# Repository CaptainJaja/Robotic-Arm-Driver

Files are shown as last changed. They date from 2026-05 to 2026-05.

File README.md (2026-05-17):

# Contrôleur "Rail-Bras-Ventouses" (STM32G4 + TMC2226)

Ce PCB est la carte de contrôle centrale du sous-système de préhension du robot. Elle orchestre les mouvements du rail, du bras et la gestion des ventouses.
Elle intègre une architecture de puissance à plusieurs étages pour gérer différents niveaux de tension (24V, 12V, 7.4V, 3.3V) à partir d'une batterie 6S, tout en pilotant une grande variété d'actionneurs via un **STM32G431**.

## ⚡ Architecture d'Alimentation (Power Tree)

L'alimentation est distribuée en cascade pour optimiser le rendement et la stabilité :

1.  **Entrée Principale :** Batterie LiPo 6S (~22.2V - 25.2V).
2.  **Étage 1 (V_BAT ➔ 12V) :** Buck **TI LM25145**.
    * *Usage :* Alimentation des Dynamixels et source pour les étages suivants.
3.  **Étage 2A (12V ➔ 7.4V) :** Buck **TI TPS563300**.
    * *Usage :* Alimentation de puissance pour les Servomoteurs classiques et les 4 moteurs DC (MCC).
4.  **Étage 2B (12V ➔ 3.3V) :** Module de puissance **Würth Elektronik MagI³C (173010x78)**.
    * *Usage :* Alimentation propre pour la logique (STM32, Capteurs).

## 🧠 Cœur Logique : STM32G431CBU6

* **MCU :** ARM Cortex-M4 à 170 MHz (Série G4 optimisée pour le contrôle moteur/mixte).
* **Programmation :** Connecteur **ST-Link** dédié (SWD).
* **Interface Utilisateur :**
    * 1x LED Power (3.3V).
    * 2x LEDs d'état (pilotables par GPIO).
    * 1x Bouton Reset.
    * 1x Bouton User (connecté sur GPIO/EXTI).

## 🦾 Contrôle Actionneurs

### 1. Axe "Rail" (Stepper) - TMC2226-SA
* **Driver :** Trinamic TMC2226 (Ultra-Silent).
* **Tension :** 24V (V_BAT).
* **Configuration :**
    * **Rsense :** 390 mΩ (Définit la plage de courant : Irms=0.56A).
    * **Microstepping :** Configurable via **DIP Switch** embarqué.
    * **Interface :** STEP / DIR + UART (Diag).
* **❄️ Gestion Thermique Avancée :**
    * Le Pad thermique du TMC2226 est soudé sur un large plan de cuivre.
    * Réseau de **vias thermiques** traversant le PCB vers une zone de cuivre exposée sur la face opposée.
    * Emplacement prévu pour coller une ailette de refroidissement (heatsink) directement sur la zone arrière.

### 2. Bras & Ventouses
* **2x Servomoteurs :** Alimentés en 7.4V (PWM direct).
* **2x Dynamixels :** Connecteurs dédiés (GND, 12V, Data).
    * *Protocole :* UART Half-Duplex (compatible protocole Robotis).
* **4x Moteurs DC (MCC) :** Sorties alimentées en 7.4V (pour pompes à vide/ventouses).

## 🔌 Connectivité & Capteurs

* **Capteur ToF (Time of Flight) :** Connecteur dédié (I2C + GPIOs + 3.3V).
* **Expansions :** 3 rangées de headers [GND - 3V3 - GPIO] pour ajouts futurs.

## 🐛 Debug & Instrumentation

Le PCB intègre des points de test (headers) regroupés pour faciliter l'analyse à l'oscilloscope ou à l'analyseur logique :

* `PWM_Servo1`, `PWM_Servo2`
* `UART_Dynamixel1`, `UART_Dynamixel2`
* `STEP`, `PDN`, `INDEX`, `DIAG` (Signaux du TMC2226)

## 🛠️ Vues du PCB

| Face Composants | Face Cuivre |
| :---: | :---: |
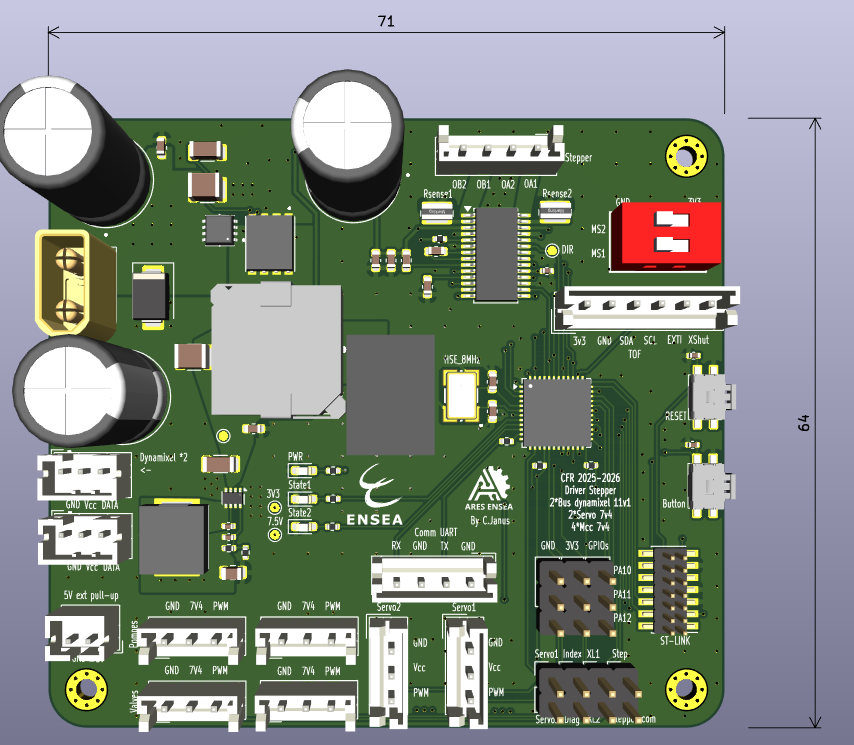
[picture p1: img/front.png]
PCB Face
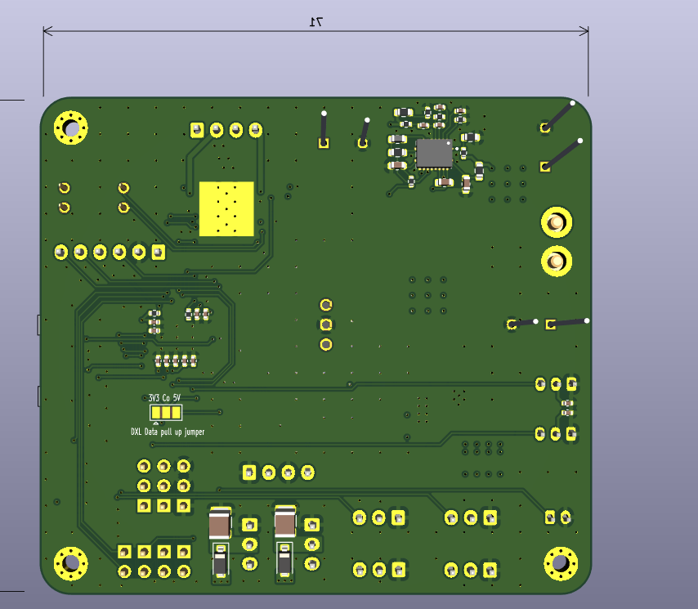
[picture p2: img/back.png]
PCB Dos
|  |  |

---
## License

This hardware project is licensed under the **CERN Open Hardware Licence Version 2 - Strongly Reciprocal (CERN-OHL-S v2)**.

You may redistribute and modify this documentation and make products using it under the terms of the CERN-OHL-S v2. If you modify or distribute this design, you must share your modifications and the entire product it is integrated into under the same open-source license.

Designed by C. Janus.

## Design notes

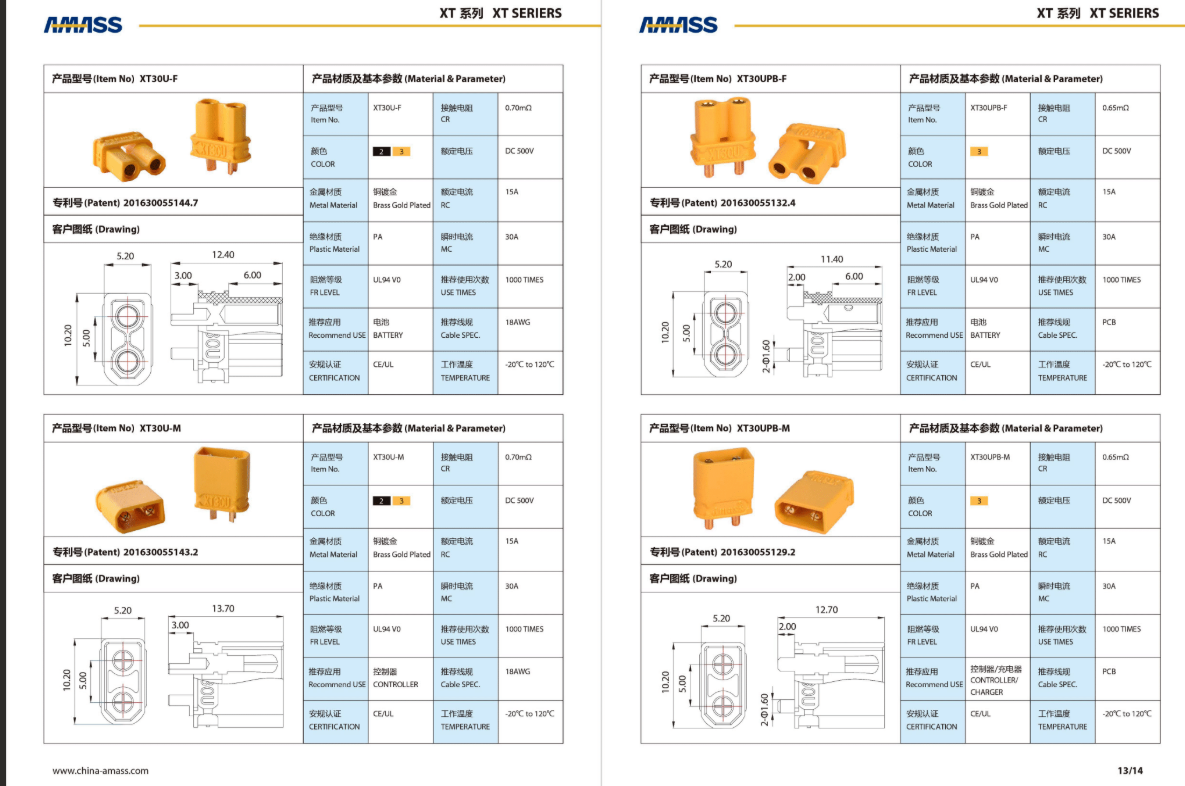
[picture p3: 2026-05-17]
datasheets/Specs_XT30.png

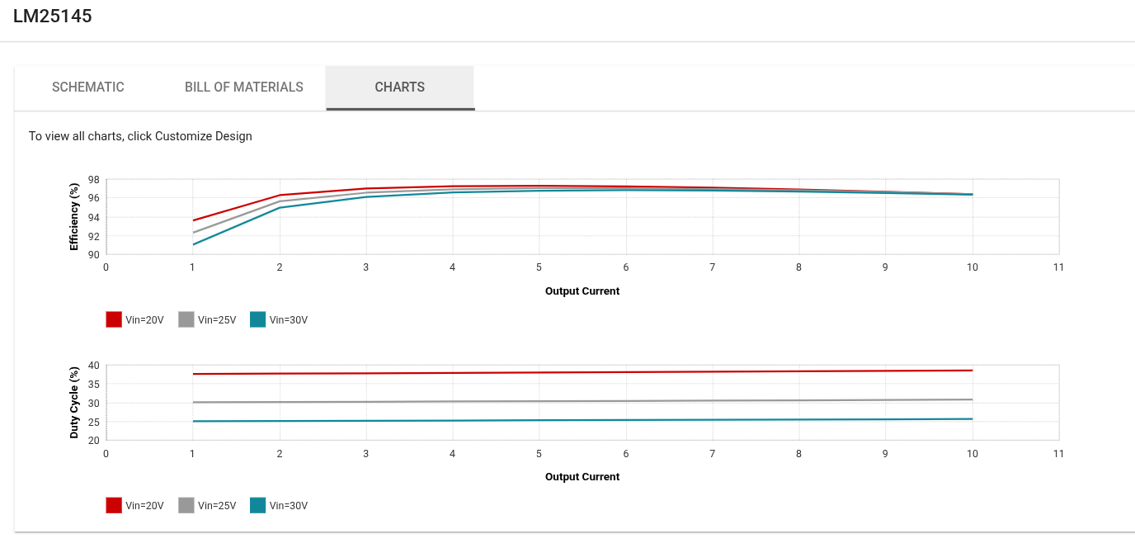
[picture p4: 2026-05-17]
Capture d’écran du 2025-11-26 16-49-32.png

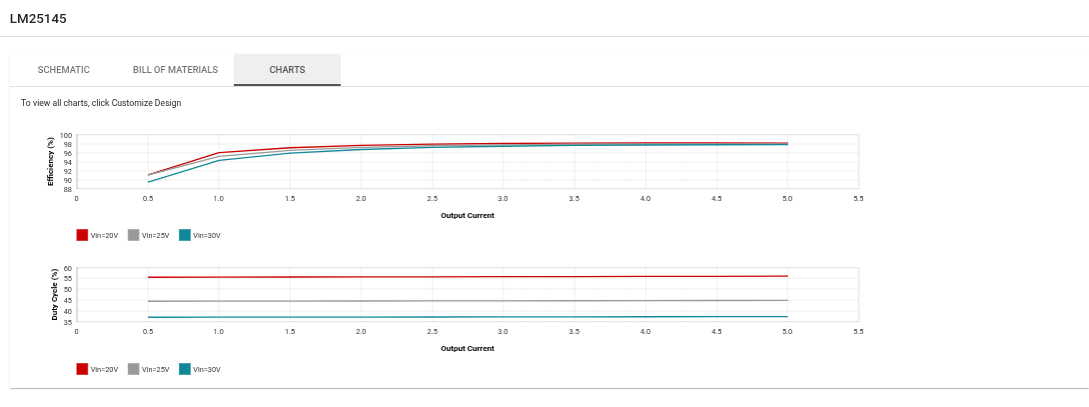
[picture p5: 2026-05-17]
Buck_11v1_XL430/charts.png

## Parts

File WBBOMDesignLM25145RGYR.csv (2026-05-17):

Part | Manufacturer | Part Number | Quantity | Price ($) | Footprint (mm²) | Description
Cbst | TDK | CGA3E2X7R1H104K080AA | 1 | 0.01 | 4.68 | Cap: 100 nF Total Derated Cap: 72 nF VDC: 50 V ESR: 29.6 mΩ Package: 0603
Ccomp1 | MuRata | GRM155R71C822KA01D | 1 | 0.01 | 3 | Cap: 8.2 nF Total Derated Cap: 8.2 nF VDC: 16 V ESR: 1 mΩ Package: 0402
Ccomp2 | MuRata | GRM155R71H821KA01D | 1 | 0.01 | 3 | Cap: 820 pF Total Derated Cap: 820 pF VDC: 50 V ESR: 1 mΩ Package: 0402
Ccomp3 | TDK | CGA2B2X7R1H471K050BA | 1 | 0.01 | 3 | Cap: 470 pF Total Derated Cap: 470 pF VDC: 50 V ESR: 4.96 Ω Package: 0402
Cilim | AVX | 06031U6R8BAT2A | 1 | 0.05 | 4.68 | Cap: 6.8 pF Total Derated Cap: 6.8 pF VDC: 100 V ESR: 0 Ω Package: 0603
Cin | Taiyo Yuden | MSASU32MSB7475MPNA01 | 1 | 0.14849 | 14.7 | Cap: 4.7 µF Total Derated Cap: 2.9 µF VDC: 50 V ESR: 6.46 mΩ Package: 1210
Cout | Taiyo Yuden | MCASE32MSB5226KPNA01 | 1 | 0.2325 | 14.7 | Cap: 22 µF Total Derated Cap: 16 µF VDC: 16 V ESR: 3.29 mΩ Package: 1210
Css | MuRata | GRM155R71C563KA88D | 1 | 0.01 | 3 | Cap: 56 nF Total Derated Cap: 56 nF VDC: 16 V ESR: 1 mΩ Package: 0402
Cvcc | TDK | CGA5L2X7R1E225K160AA | 1 | 0.08389 | 10.92 | Cap: 2.2 µF Total Derated Cap: 2.2 µF VDC: 25 V ESR: 4 mΩ Package: 1206
Cvin | TDK | CGA3E2X7R1H104K080AA | 1 | 0.01 | 4.68 | Cap: 100 nF Total Derated Cap: 72 nF VDC: 50 V ESR: 29.6 mΩ Package: 0603
L1 | Bourns | SRP1270-4R7M | 1 | 0.83 | 246.49 | L: 4.7 µH DCR: 11.2 mΩ IDC: 15 A
M1 | Texas Instruments | CSD18543Q3A | 1 | 0.21 | 18.49 | VdsMax: 60 V IdsMax: 35 Amps
M2 | Texas Instruments | CSD18513Q5A | 1 | 0.26 | 55.2 | VdsMax: 40 V IdsMax: 100 Amps
Rcomp1 | Vishay-Dale | CRCW04021K65FKED | 1 | 0.01 | 3 | Resistance: 1.65 kΩ Tolerance: 1.0% Power: 63 mW
Rcomp2 | Vishay-Dale | CRCW0402110RFKED | 1 | 0.01 | 3 | Resistance: 110 Ω Tolerance: 1.0% Power: 63 mW
Rfbb | Vishay-Dale | CRCW04022K15FKED | 1 | 0.01 | 3 | Resistance: 2.15 kΩ Tolerance: 1.0% Power: 63 mW
Rfbt | Yageo | RC0603FR-0718KL | 1 | 0.01 | 4.68 | Resistance: 18 kΩ Tolerance: 1.0% Power: 100 mW
Rilim | Vishay-Dale | CRCW04021K21FKED | 1 | 0.01 | 3 | Resistance: 1.21 kΩ Tolerance: 1.0% Power: 63 mW
Rpgood | Yageo | RC0603FR-0720KL | 1 | 0.01 | 4.68 | Resistance: 20 kΩ Tolerance: 1.0% Power: 100 mW
Rt | Vishay-Dale | CRCW040239K2FKED | 1 | 0.01 | 3 | Resistance: 39.2 kΩ Tolerance: 1.0% Power: 63 mW
Ruv1 | Vishay-Dale | CRCW0402100KFKED | 1 | 0.01 | 3 | Resistance: 100 kΩ Tolerance: 1.0% Power: 63 mW
Ruv2 | Vishay-Dale | CRCW06038K06FKEA | 1 | 0.01 | 4.68 | Resistance: 8.06 kΩ Tolerance: 1.0% Power: 100 mW
Rvin | Vishay-Dale | CRCW06032R10FKEA | 1 | 0.01 | 4.68 | Resistance: 2.1 Ω Tolerance: 1.0% Power: 100 mW
U1 | Texas Instruments | LM25145RGYR | 1 | 0.949 | 24.75
Rvcc | Yageo | RC0603FR-0720KL | 1 | 0.01 | 4.68 | Resistance: 20 kΩ Tolerance: 1.0% Power: 100 mW

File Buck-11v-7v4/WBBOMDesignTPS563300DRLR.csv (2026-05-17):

Part | Manufacturer | Part Number | Quantity | Price ($) | Footprint (mm²) | Description
U1 | Texas Instruments | TPS563300DRLR | 1 | 0.375 | 8.06
Cinx | AVX | 06033C104KAT2A | 1 | 0.01 | 4.68 | Cap: 100 nF Total Derated Cap: 100 nF VDC: 25 V ESR: 50 mΩ Package: 0603
Cout | Taiyo Yuden | MSAST21GBB5106MTNA01 | 3 | 0.03995 | 6.75 | Cap: 10 µF Total Derated Cap: 13 µF VDC: 25 V ESR: 5.46 mΩ Package: 0805
L1 | Bourns | SDE1006A-5R6M | 1 | 0.43 | 132 | L: 5.6 µH DCR: 40 mΩ IDC: 4.5 A
Cin | MuRata | GRM21BR61E106MA73L | 1 | 0.04 | 6.75 | Cap: 10 µF Total Derated Cap: 1.7 µF VDC: 25 V ESR: 4 mΩ Package: 0805
Cboot | TDK | C0603X5R1A104K030BC | 1 | 0.01189 | 2.08 | Cap: 100 nF Total Derated Cap: 100 nF VDC: 10 V ESR: 70 mΩ Package: 0201
Cff | MuRata | GRM0335C1E470JA01D | 1 | 0.01 | 2.08 | Cap: 47 pF Total Derated Cap: 47 pF VDC: 25 V ESR: 0 Ω Package: 0201
Rfbb | Vishay-Dale | CRCW040210K0FKED | 1 | 0.01 | 3 | Resistance: 10 kΩ Tolerance: 1.0% Power: 63 mW
Rfbt | Vishay-Dale | CRCW040284K5FKED | 1 | 0.01 | 3 | Resistance: 84.5 kΩ Tolerance: 1.0% Power: 63 mW

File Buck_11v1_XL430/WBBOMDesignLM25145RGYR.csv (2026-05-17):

Part | Manufacturer | Part Number | Quantity | Price ($) | Footprint (mm²) | Description
Cbst | TDK | CGA3E2X7R1H104K080AA | 1 | 0.01 | 4.68 | Cap: 100 nF Total Derated Cap: 72 nF VDC: 50 V ESR: 29.6 mΩ Package: 0603
Ccomp1 | MuRata | GRM155R71C822KA01D | 1 | 0.01 | 3 | Cap: 8.2 nF Total Derated Cap: 8.2 nF VDC: 16 V ESR: 1 mΩ Package: 0402
Ccomp2 | TDK | CGA2B2X7R1H471K050BA | 1 | 0.01 | 3 | Cap: 470 pF Total Derated Cap: 470 pF VDC: 50 V ESR: 4.96 Ω Package: 0402
Ccomp3 | TDK | CGA2B2X7R1H681K050BA | 1 | 0.01 | 3 | Cap: 680 pF Total Derated Cap: 680 pF VDC: 50 V ESR: 3.08 Ω Package: 0402
Cilim | MuRata | GRM1885C2A100JA01D | 1 | 0.02 | 4.68 | Cap: 10 pF Total Derated Cap: 10 pF VDC: 100 V ESR: 1 mΩ Package: 0603
Cin | Taiyo Yuden | MSASU32MSB7475MPNA01 | 1 | 0.14849 | 14.7 | Cap: 4.7 µF Total Derated Cap: 2.9 µF VDC: 50 V ESR: 6.46 mΩ Package: 1210
Cout | Taiyo Yuden | MSAST32MSB7226KPNB25 | 2 | 0.18132 | 14.7 | Cap: 22 µF Total Derated Cap: 15 µF VDC: 25 V ESR: 3.3 mΩ Package: 1210
Css | MuRata | GRM155R71C563KA88D | 1 | 0.01 | 3 | Cap: 56 nF Total Derated Cap: 56 nF VDC: 16 V ESR: 1 mΩ Package: 0402
Cvcc | TDK | CGA5L2X7R1E225K160AA | 1 | 0.08389 | 10.92 | Cap: 2.2 µF Total Derated Cap: 2.2 µF VDC: 25 V ESR: 4 mΩ Package: 1206
Cvin | TDK | CGA3E2X7R1H104K080AA | 1 | 0.01 | 4.68 | Cap: 100 nF Total Derated Cap: 72 nF VDC: 50 V ESR: 29.6 mΩ Package: 0603
L1 | Coilcraft | DO5040H-123MLB | 1 | 0.98 | 444.63 | L: 12 µH DCR: 11.7 mΩ IDC: 7.4 A
M1 | Texas Instruments | CSD18543Q3A | 1 | 0.21 | 18.49 | VdsMax: 60 V IdsMax: 35 Amps
M2 | Texas Instruments | CSD18514Q5A | 1 | 0.22 | 55.2 | VdsMax: 40 V IdsMax: 50 Amps
Rcomp1 | Vishay-Dale | CRCW04022K61FKED | 1 | 0.01 | 3 | Resistance: 2.61 kΩ Tolerance: 1.0% Power: 63 mW
Rcomp2 | Vishay-Dale | CRCW040237R4FKED | 1 | 0.01 | 3 | Resistance: 37.4 Ω Tolerance: 1.0% Power: 63 mW
Rfbb | Vishay-Dale | CRCW04021K40FKED | 1 | 0.01 | 3 | Resistance: 1.4 kΩ Tolerance: 1.0% Power: 63 mW
Rfbt | Yageo | RC0603FR-0718KL | 1 | 0.01 | 4.68 | Resistance: 18 kΩ Tolerance: 1.0% Power: 100 mW
Rilim | Vishay-Dale | CRCW0402511RFKED | 1 | 0.01 | 3 | Resistance: 511 Ω Tolerance: 1.0% Power: 63 mW
Rpgood | Yageo | RC0603FR-0720KL | 1 | 0.01 | 4.68 | Resistance: 20 kΩ Tolerance: 1.0% Power: 100 mW
Rt | Vishay-Dale | CRCW040239K2FKED | 1 | 0.01 | 3 | Resistance: 39.2 kΩ Tolerance: 1.0% Power: 63 mW
Ruv1 | Vishay-Dale | CRCW0402100KFKED | 1 | 0.01 | 3 | Resistance: 100 kΩ Tolerance: 1.0% Power: 63 mW
Ruv2 | Vishay-Dale | CRCW06038K06FKEA | 1 | 0.01 | 4.68 | Resistance: 8.06 kΩ Tolerance: 1.0% Power: 100 mW
Rvin | Vishay-Dale | CRCW06032R10FKEA | 1 | 0.01 | 4.68 | Resistance: 2.1 Ω Tolerance: 1.0% Power: 100 mW
U1 | Texas Instruments | LM25145RGYR | 1 | 0.949 | 24.75
Rvcc | Yageo | RC0603FR-0720KL | 1 | 0.01 | 4.68 | Resistance: 20 kΩ Tolerance: 1.0% Power: 100 mW

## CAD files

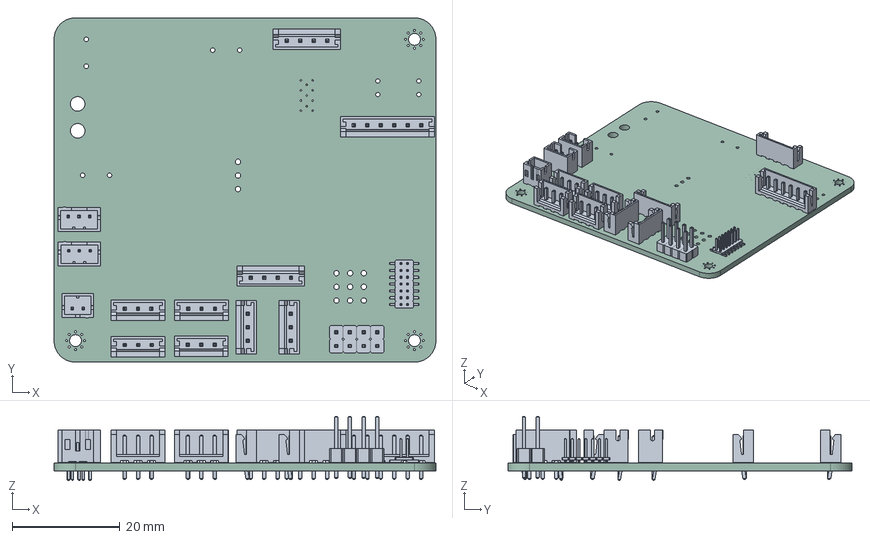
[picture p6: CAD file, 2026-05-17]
PCB_RAIL/PCB_RAIL.step
71.0 x 64.0 x 11.9 mm
JST_PH_B2B-PH-K_1x02_P2.00mm_Vertical
JST_EH_B3B-EH-A_1x03_P2.50mm_Vertical x 6
PinHeader_2x07_P1.27mm_Vertical_SMD
JST_EH_B4B-EH-A_1x04_P2.50mm_Vertical x 2
PinHeader_1x02_P2.54mm_Vertical x 4
JST_EH_B6B-EH-A_1x06_P2.50mm_Vertical
JST_PH_B3B-PH-K_1x03_P2.00mm_Vertical x 2
PCB_RAIL_PCB

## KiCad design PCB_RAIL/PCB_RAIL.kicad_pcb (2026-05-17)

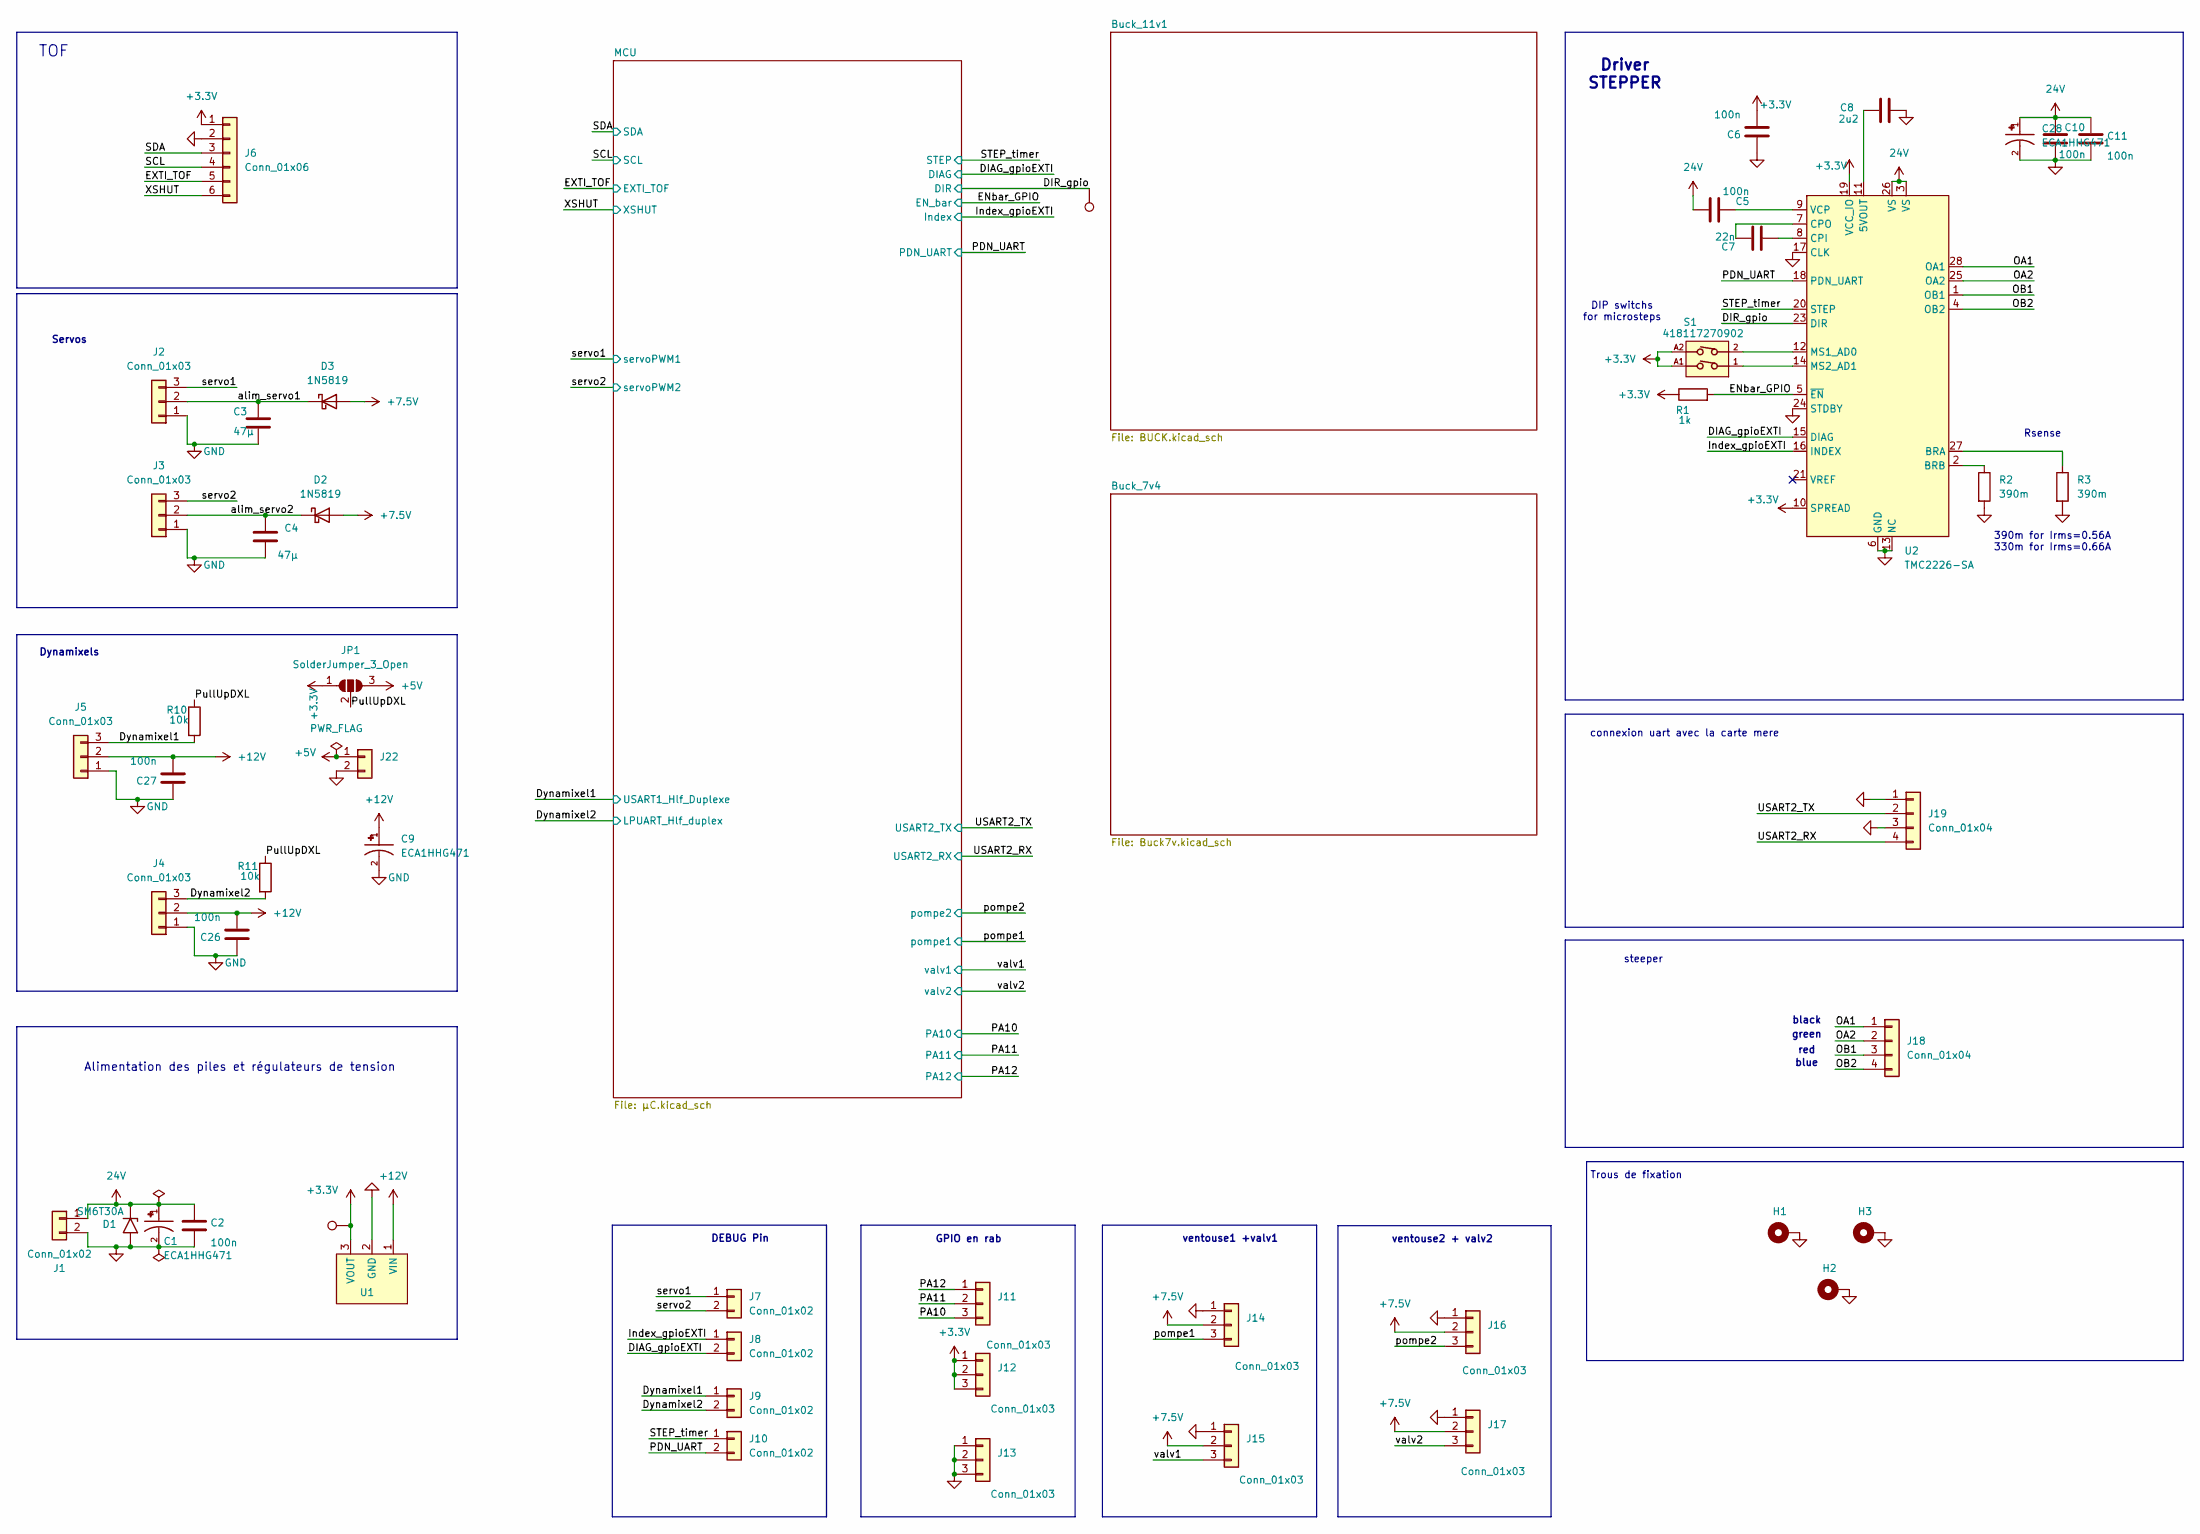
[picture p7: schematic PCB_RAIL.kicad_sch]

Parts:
C1, C9, C28: ECA1HHG471; PARTREV 20-DEC-19
C2, C5, C10, C11: 100n; C_0603_1608Metric
C3, C4: 47µ; C_1210_3225Metric
C6, C26, C27: 100n; C_0402_1005Metric
C7: 22n; C_0603_1608Metric
C8: 2u2; C_0603_1608Metric
D1: SM6T30A; D_SMB
D2, D3: 1N5819; D_SOD-123
H1, H2, H3: MountingHole_Pad; MountingHole_2.2mm_M2_Pad_Via
J1: Conn_01x02; XT30-F-2P
J2, J3, J14, J15, J16, J17: Conn_01x03; JST_EH_B3B-EH-A_1x03_P2.50mm_Vertical
J4, J5: Conn_01x03; JST_PH_B3B-PH-K_1x03_P2.00mm_Vertical
J6: Conn_01x06; JST_EH_B6B-EH-A_1x06_P2.50mm_Vertical
J7, J8, J9, J10: Conn_01x02; PinHeader_1x02_P2.54mm_Vertical
J11, J12, J13: Conn_01x03; PinHeader_1x03_P2.54mm_Vertical
J18, J19: Conn_01x04; JST_EH_B4B-EH-A_1x04_P2.50mm_Vertical
J22: Conn_01x02; JST_PH_B2B-PH-K_1x02_P2.00mm_Vertical
JP1: SolderJumper_3_Open; SolderJumper-3_P1.3mm_Open_Pad1.0x1.5mm
R1: 1k; R_0402_1005Metric
R2, R3: 390m; 561070332071
R10, R11: 10k; R_0402_1005Metric
S1: 418117270902
TP1, TP2: TestPoint; TestPoint_Pad_D1.0mm
U1: WPME-FDSM_17301XX35; MPN 173010x78
U2: TMC2226-SA; TMC2226

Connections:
24V: C1.1, C2.1, C5.1, C10.1, C11.1, C28.1, D1.1 (A1), J1.1, U2.3 (VS), U2.26 (VS); also elsewhere on the board
+3.3V: C6.2, J6.1, J12.1, J12.2, J12.3, JP1.1 (A), R1.1, S1.A1, S1.A2, TP1.1, U1.3 (VOUT), U2.10 (SPREAD), U2.19 (VCC_IO); also elsewhere on the board
+5V: J22.1, JP1.3 (B)
+7.5V: D2.2 (A), D3.2 (A), J14.2, J15.2, J16.2, J17.2; also elsewhere on the board
+12V: C9.1, C26.2, C27.2, J4.2, J5.2, U1.1 (VIN); also elsewhere on the board
/DIAG_gpioEXTI: J8.2, U2.15 (DIAG); also elsewhere on the board
/DIR_gpio: TP2.1, U2.23 (DIR); also elsewhere on the board
/Dynamixel1: J5.3, J9.1, R10.2; also elsewhere on the board
/Dynamixel2: J4.3, J9.2, R11.2; also elsewhere on the board
/ENbar_GPIO: R1.2, U2.5 (~EN); also elsewhere on the board
/EXTI_TOF: J6.5; also elsewhere on the board
/Index_gpioEXTI: J8.1, U2.16 (INDEX); also elsewhere on the board
/OA1: J18.1, U2.28 (OA1)
/OA2: J18.2, U2.25 (OA2)
/OB1: J18.3, U2.1 (OB1)
/OB2: J18.4, U2.4 (OB2)
/PA10: J11.3; also elsewhere on the board
/PA11: J11.2; also elsewhere on the board
/PA12: J11.1; also elsewhere on the board
/PDN_UART: J10.2, U2.18 (PDN_UART); also elsewhere on the board
/PullUpDXL: JP1.2 (C), R10.1, R11.1
/SCL: J6.4; also elsewhere on the board
/SDA: J6.3; also elsewhere on the board
/STEP_timer: J10.1, U2.20 (STEP); also elsewhere on the board
/USART2_RX: J19.4; also elsewhere on the board
/USART2_TX: J19.2; also elsewhere on the board
/XSHUT: J6.6; also elsewhere on the board
/alim_servo1: C3.1, D3.1 (K), J2.2
/alim_servo2: C4.1, D2.1 (K), J3.2
/pompe1: J14.3; also elsewhere on the board
/pompe2: J16.3; also elsewhere on the board
/servo1: J2.3, J7.1; also elsewhere on the board
/servo2: J3.3, J7.2; also elsewhere on the board
/valv1: J15.3; also elsewhere on the board
/valv2: J17.3; also elsewhere on the board
GND: C1.2, C2.2, C3.2, C4.2, C6.1, C8.1, C9.2, C10.2, C11.2, C26.1, C27.1, C28.2, D1.2 (A2), H1.1, H2.1, H3.1, J1.2, J2.1, J3.1, J4.1, J5.1, J6.2, J13.1, J13.2, J13.3, J14.1, J15.1, J16.1, J17.1, J19.1, J19.3, J22.2, R2.2, R3.2, U1.2 (GND), U2.6 (GND), U2.13 (NC), U2.17 (CLK), U2.22 (GND), U2.24 (STDBY), U2.29 (GND); also elsewhere on the board
unnamed: C8.2, U2.11 (5VOUT)
unnamed: R3.1, U2.27 (BRA)
unnamed: R2.1, U2.2 (BRB)
unnamed: C7.2, U2.8 (CPI)
unnamed: C7.1, U2.7 (CPO)
unnamed: S1.2, U2.12 (MS1_AD0)
unnamed: S1.1, U2.14 (MS2_AD1)
unnamed: C5.2, U2.9 (VCP)

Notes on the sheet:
DEBUG Pin
green
Trous de fixation
ventouse2 + valv2
Alimentation des piles et régulateurs de tension
Driver STEPPER
Servos
connexion uart avec la carte mere
red
Dynamixels
Rsense
TOF
ventouse1 +valv1
blue
390m for Irms=0.56A 330m for Irms=0.66A
steeper
DIP switchs for microsteps
black
GPIO en rab

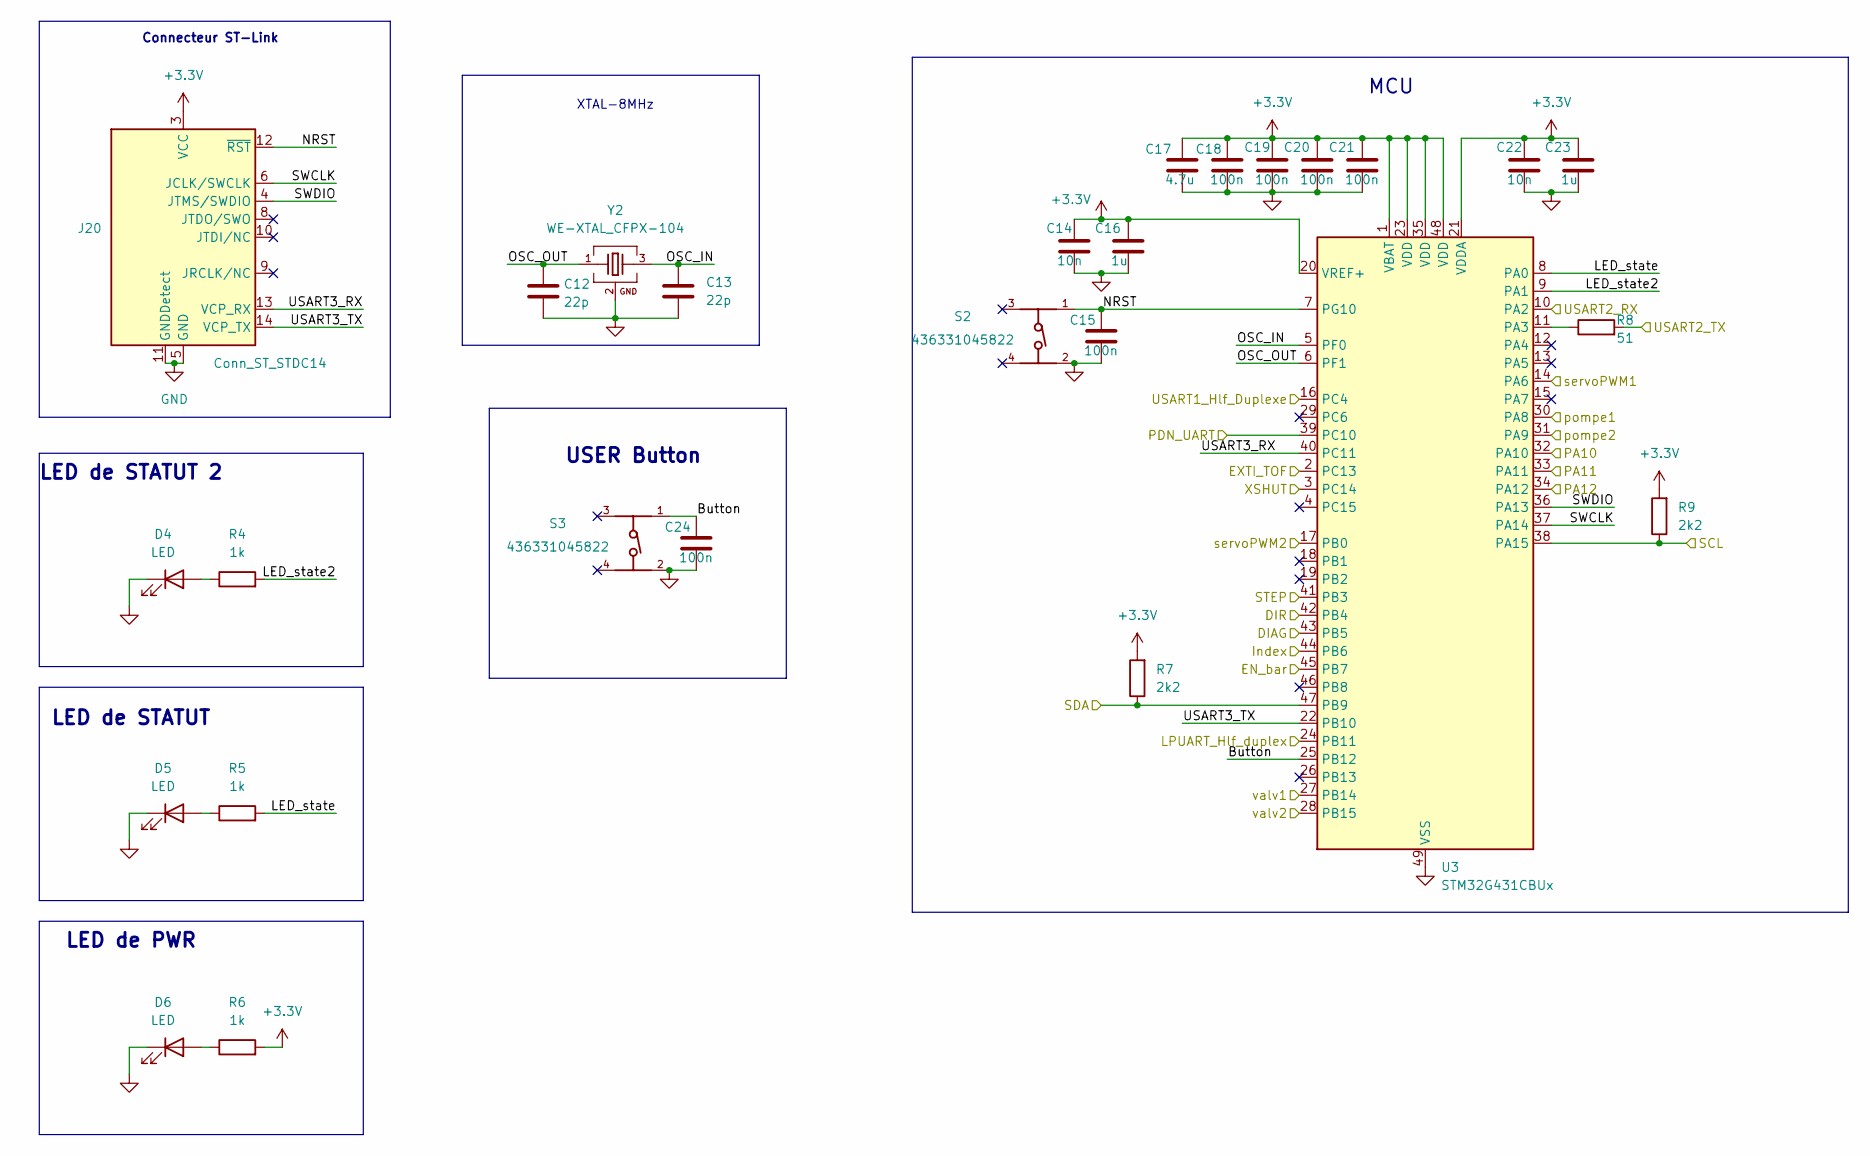
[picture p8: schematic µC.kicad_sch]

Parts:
C12, C13: 22p; C_0603_1608Metric
C14, C22: 10n; C_0402_1005Metric
C15, C18, C19, C20, C21, C24: 100n; C_0402_1005Metric
C16, C23: 1u; C_0402_1005Metric
C17: 4.7u; C_0402_1005Metric
D4, D5, D6: LED; LED_0603_1608Metric_Pad1.05x0.95mm_HandSolder
J20: Conn_ST_STDC14; PinHeader_2x07_P1.27mm_Vertical_SMD
R4, R5, R6: 1k; R_0402_1005Metric
R7, R9: 2k2; R_0402_1005Metric
R8: 51; R_0402_1005Metric
S2, S3: 436331045822
U3: STM32G431CBUx; STM32G431CBU6
Y2: WE-XTAL_CFPX-104; DigiKey_Part_Number 1923-830055663CT-ND

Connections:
+3.3V: C14.1, C16.1, C17.1, C18.1, C19.1, C20.1, C21.1, C22.1, C23.1, J20.3 (VCC), R6.2, R7.2, R9.2, U3.1 (VBAT), U3.20 (VREF+), U3.21 (VDDA), U3.23 (VDD), U3.35 (VDD), U3.48 (VDD); also elsewhere on the board
/DIAG_gpioEXTI: U3.43 (PB5); also elsewhere on the board
/DIR_gpio: U3.42 (PB4); also elsewhere on the board
/Dynamixel1: U3.16 (PC4); also elsewhere on the board
/Dynamixel2: U3.24 (PB11); also elsewhere on the board
/ENbar_GPIO: U3.45 (PB7); also elsewhere on the board
/EXTI_TOF: U3.2 (PC13); also elsewhere on the board
/Index_gpioEXTI: U3.44 (PB6); also elsewhere on the board
/MCU/Button: C24.1, S3.1, U3.25 (PB12)
/MCU/LED_state: R5.2, U3.8 (PA0)
/MCU/LED_state2: R4.2, U3.9 (PA1)
/MCU/NRST: C15.1, J20.12 (~RST), S2.1, U3.7 (PG10)
/MCU/OSC_IN: C13.1, U3.5 (PF0), Y2.3
/MCU/OSC_OUT: C12.1, U3.6 (PF1), Y2.1
/MCU/SWCLK: J20.6 (JCLK/SWCLK), U3.37 (PA14)
/MCU/SWDIO: J20.4 (JTMS/SWDIO), U3.36 (PA13)
/MCU/USART3_RX: J20.13 (VCP_RX), U3.40 (PC11)
/MCU/USART3_TX: J20.14 (VCP_TX), U3.22 (PB10)
/PA10: U3.32 (PA10); also elsewhere on the board
/PA11: U3.33 (PA11); also elsewhere on the board
/PA12: U3.34 (PA12); also elsewhere on the board
/PDN_UART: U3.39 (PC10); also elsewhere on the board
/SCL: R9.1, U3.38 (PA15); also elsewhere on the board
/SDA: R7.1, U3.47 (PB9); also elsewhere on the board
/STEP_timer: U3.41 (PB3); also elsewhere on the board
/USART2_RX: U3.10 (PA2); also elsewhere on the board
/USART2_TX: R8.2; also elsewhere on the board
/XSHUT: U3.3 (PC14); also elsewhere on the board
/pompe1: U3.30 (PA8); also elsewhere on the board
/pompe2: U3.31 (PA9); also elsewhere on the board
/servo1: U3.14 (PA6); also elsewhere on the board
/servo2: U3.17 (PB0); also elsewhere on the board
/valv1: U3.27 (PB14); also elsewhere on the board
/valv2: U3.28 (PB15); also elsewhere on the board
GND: C12.2, C13.2, C14.2, C15.2, C16.2, C17.2, C18.2, C19.2, C20.2, C21.2, C22.2, C23.2, C24.2, D4.1 (K), D5.1 (K), D6.1 (K), J20.5 (GND), J20.7 (GND), J20.11 (GNDDetect), S2.2, S3.2, U3.49 (VSS), Y2.2, Y2.4; also elsewhere on the board
unnamed: D4.2 (A), R4.1
unnamed: D5.2 (A), R5.1
unnamed: D6.2 (A), R6.1
unnamed: R8.1, U3.11 (PA3)

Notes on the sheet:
LED de STATUT 2
LED de STATUT
XTAL-8MHz
LED de PWR
Connecteur ST-Link
USER Button
MCU

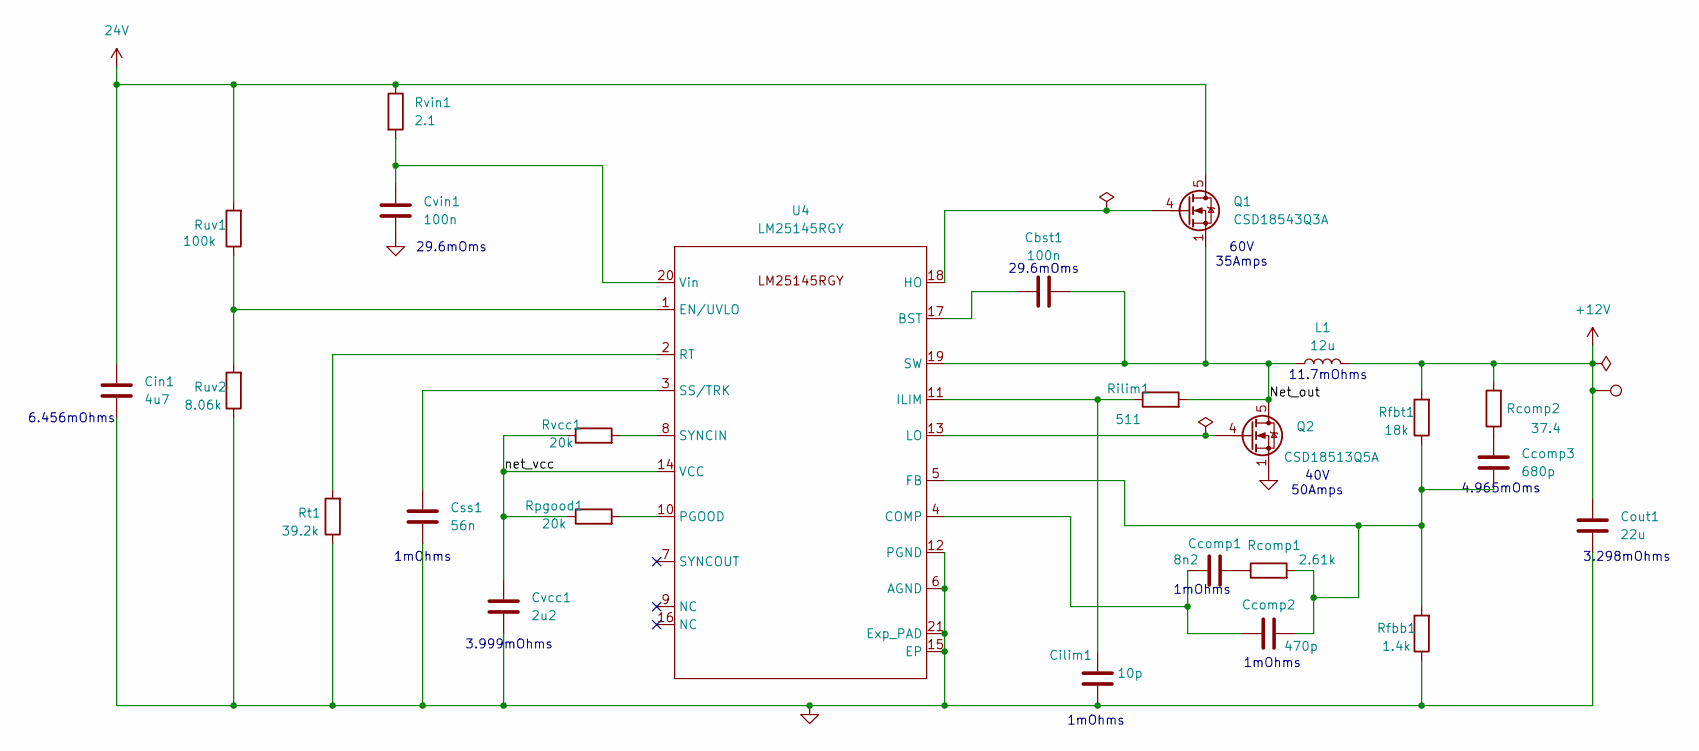
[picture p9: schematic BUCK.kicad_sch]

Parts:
Cbst1: 100n; C_0603_1608Metric
Ccomp1: 8n2; C_0402_1005Metric
Ccomp2: 470p; C_0402_1005Metric
Ccomp3: 680p; C_0402_1005Metric
Cilim1: 10p; C_0603_1608Metric
Cin1: 4u7; C_1210_3225Metric
Cout1: 22u; C_1210_3225Metric
Css1: 56n; C_0402_1005Metric
Cvcc1: 2u2; C_1206_3216Metric
Cvin1: 100n; C_0603_1608Metric
L1: 12u; L_12x12mm_H8mm
Q1: CSD18543Q3A; TRANS_CSD18543Q3A
Q2: CSD18513Q5A; TRANS_CSD18534Q5A
Rcomp1: 2.61k; R_0402_1005Metric
Rcomp2: 37.4; R_0402_1005Metric
Rfbb1: 1.4k; R_0402_1005Metric
Rfbt1: 18k; R_0603_1608Metric
Rilim1: 511; R_0402_1005Metric
Rpgood1: 20k; R_0603_1608Metric
Rt1: 39.2k; R_0402_1005Metric
Ruv1: 100k; R_0402_1005Metric
Ruv2: 8.06k; R_0603_1608Metric
Rvcc1: 20k; L_0603_1608Metric
Rvin1: 2.1; R_0603_1608Metric
TP3: TestPoint; TestPoint_Pad_D1.0mm
U4: LM25145RGY; IC_LM25145RGYR

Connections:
24V: Cin1.1, Q1.5 (D), Ruv1.2, Rvin1.1; also elsewhere on the board
+12V: Cout1.2, L1.2, Rcomp2.2, Rfbt1.2, TP3.1; also elsewhere on the board
/Buck_11v1/Net_out: Cbst1.2, L1.1, Q1.1 (S), Q1.2 (S), Q1.3 (S), Q2.5 (D), Rilim1.2, U4.19 (SW)
/Buck_11v1/net_vcc: Cvcc1.1, Rpgood1.1, Rvcc1.1, U4.14 (VCC)
GND: Cilim1.2, Cin1.2, Cout1.1, Css1.2, Cvcc1.2, Cvin1.2, Q2.1 (S), Q2.2 (S), Q2.3 (S), Rfbb1.1, Rt1.1, Ruv2.1, U4.6 (AGND), U4.12 (PGND), U4.15 (EP), U4.21 (Exp_PAD); also elsewhere on the board
unnamed: Ccomp1.1, Rcomp1.1
unnamed: Ccomp3.2, Rcomp2.1
unnamed: Q1.4 (G), U4.18 (HO)
unnamed: Q2.4 (G), U4.13 (LO)
unnamed: Cbst1.1, U4.17 (BST)
unnamed: Ccomp1.2, Ccomp2.2, U4.4 (COMP)
unnamed: Ruv1.1, Ruv2.2, U4.1 (EN/UVLO)
unnamed: Ccomp2.1, Ccomp3.1, Rcomp1.2, Rfbb1.2, Rfbt1.1, U4.5 (FB)
unnamed: Cilim1.1, Rilim1.1, U4.11 (ILIM)
unnamed: Rpgood1.2, U4.10 (PGOOD)
unnamed: Rt1.2, U4.2 (RT)
unnamed: Css1.1, U4.3 (SS/TRK)
unnamed: Rvcc1.2, U4.8 (SYNCIN)
unnamed: Cvin1.1, Rvin1.2, U4.20 (Vin)

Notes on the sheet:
1mOhms
3.999mOhms
29.6mOms
60V 35Amps
40V 50Amps
11.7mOhms
3.298mOhms
1mOhms
4.965mOms
6.456mOhms

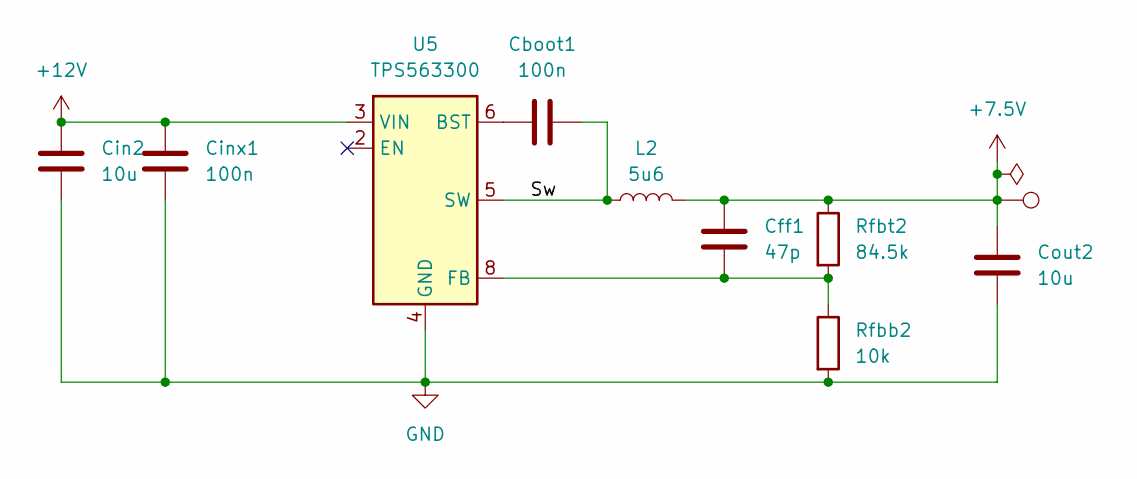
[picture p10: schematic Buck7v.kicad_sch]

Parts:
Cboot1: 100n; C_0402_1005Metric
Cff1: 47p; C_0402_1005Metric
Cin2: 10u; C_1206_3216Metric
Cinx1: 100n; C_0603_1608Metric
Cout2: 10u; C_0805_2012Metric
L2: 5u6; IND_ECS-MPIL0630-5R6MC
Rfbb2: 10k; R_0402_1005Metric
Rfbt2: 84.5k; R_0402_1005Metric
TP4: TestPoint; TestPoint_Pad_D1.0mm
U5: TPS563300; SOT-583-8

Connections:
+7.5V: Cff1.1, Cout2.1, L2.2, Rfbt2.1, TP4.1; also elsewhere on the board
+12V: Cin2.1, Cinx1.1, U5.3 (VIN); also elsewhere on the board
/Buck_7v4/Sw: Cboot1.2, L2.1, U5.5 (SW)
GND: Cin2.2, Cinx1.2, Cout2.2, Rfbb2.2, U5.4 (GND); also elsewhere on the board
unnamed: Cboot1.1, U5.6 (BST)
unnamed: Cff1.2, Rfbb2.1, Rfbt2.2, U5.8 (FB)

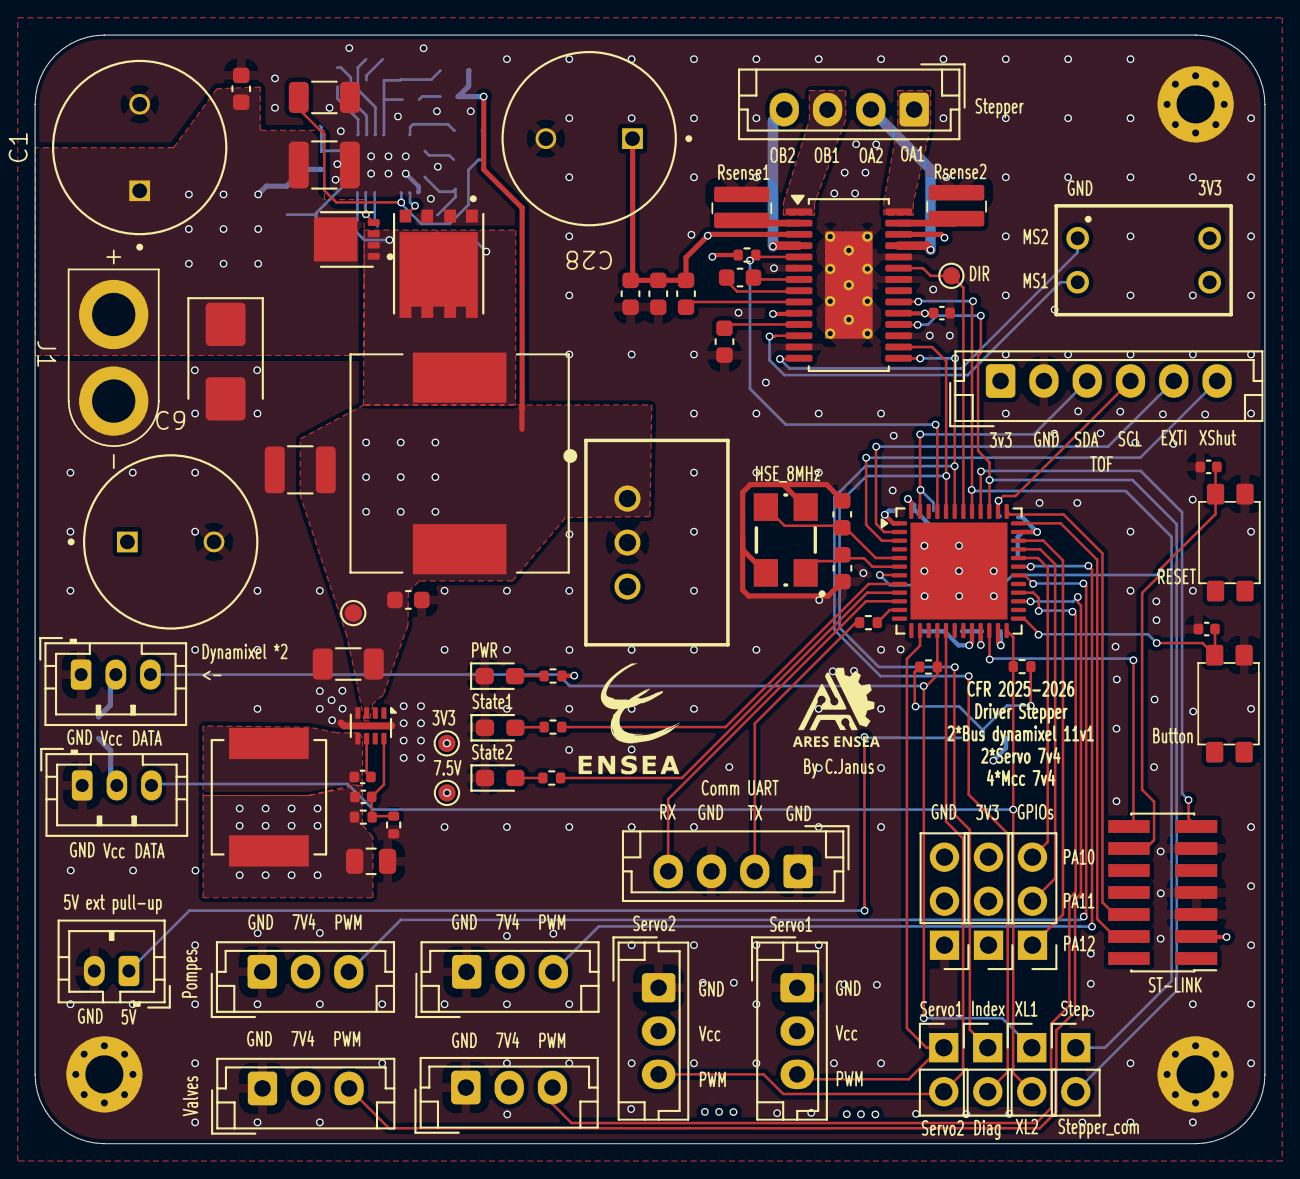
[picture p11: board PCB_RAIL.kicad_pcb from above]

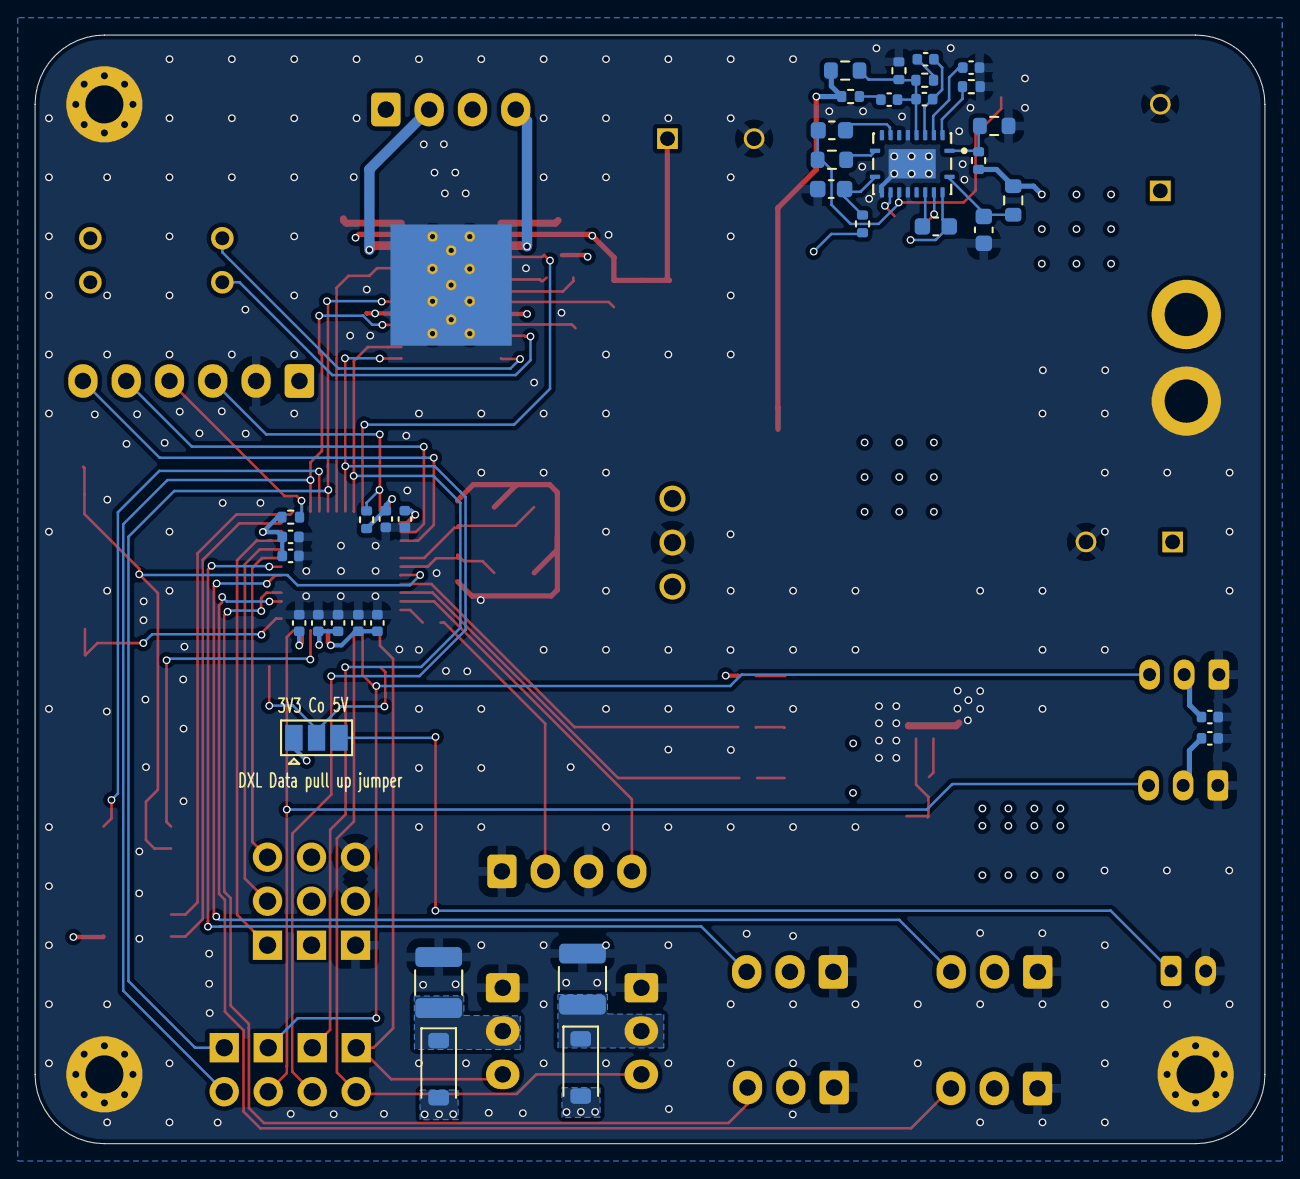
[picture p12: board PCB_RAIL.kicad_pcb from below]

Board: 4 copper layers, 71.0 x 64.0 mm, 114 parts (37 on the bottom side), 77 nets.

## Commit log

2026-05-17 Publication du projet sur github
    [BUCK.kicad_sch, Buck7v.kicad_sch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]
2026-05-17 final push readme+3d
    [BUCK.kicad_sch, Buck7v.kicad_sch, PCB_RAIL.kicad_pcb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]
